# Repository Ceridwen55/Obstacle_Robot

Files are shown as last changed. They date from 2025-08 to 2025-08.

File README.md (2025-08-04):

## 🤖 Wall Avoiding Robot (TM4C1294XL + PWM + Sharp IR Sensor)

A lightweight wall-avoiding robot built with the TM4C1294XL LaunchPad, using real analog sensor data and low-level embedded programming. No RTOS ( I dont think I need to implement this due to simple scheduling situation ), no Arduino. Just C, timers, ADCs, and PWM. Great for learning direct hardware control. I'm mixing DRM and TivaWare due to ADC RIS didn't work with my intention with using DRM only method, so that's that

---

## 🚀 Overview

The robot moves forward and avoids obstacles using two DC motors and two Sharp IR sensors. It reads distance on the left and right, calculates the error, and adjusts each motor's PWM speed to steer accordingly.

It uses:

- **SysTick timer** for generating PWM
- **ADC0 Sequencer 2** to read analog values from Sharp GP2Y0A21YK0F sensors (PE2 and PE3)
- **Bare-metal C programming** using TivaWare API
- **Empirical distance calibration formula** to convert ADC values into actual distance

---

## 📐 Core Logic

1. **PWM control using SysTick:**  
   Timer fires at 16 kHz. Each motor gets a PWM signal. PWM values are updated based on the sensor readings.

2. **Analog sensor readings (ADC):**  
   PE2 and PE3 (AIN1 and AIN0) are used for right and left distance sensors. ADC sequencer 2 reads both at once.

3. **Distance calculation:**  
   Distance (cm) = 114251 / ADC_Value
(Empirically derived constant for GP2Y0A21YK0F)

## Decision-making:
The difference between left and right distance determines motor speed difference. 

Logic:

If the robot is too close on one side → slow that side's motor

If both sides are balanced → move forward

## 🧠 Behavior Table

Condition	Action
error > 100	Turn left (slow right motor)
error < -100	Turn right (slow left motor)
-100 <= error <= 100	Move forward (equal speed)

## 📦 Hardware Bill of Materials (BoM)

| Component | Quantity | Notes |
|---|---|---|
| TM4C1294XL LaunchPad | 1 | Main MCU board |
| DC Motors (3–7V, F130 type) | 2 | For driving the wheels |
| Sharp IR Sensor (GP2Y0A21YK0F) | 2 | Distance sensing front-left and front-right|
| IRLB3034 / TIP120 Transistors | 2 | Motor driver (TIP120 used due to logic voltage compatibility) | ( *Yup this is too far right lol* )
| Diode 1N4002 | 2 | Flyback protection |
| Capacitor 10µF | 2 | Noise filtering |
| L7805CV Voltage Regulator | 1 | For 5V output to sensors & MCU |
| Resistor 220Ω | 2 | Gate resistor for transistor |
| Resistor 10kΩ | 2 | Pull-down on transistor gate |
| LM2596 Buck Converter | 1 | Optional for efficient power delivery |
| Li-Ion Batteries (3.7V) | 3 | Power source |
| Battery Holder (3-slot) | 1 | For 3S battery configuration |
| Robot chassis + wheels | 1 set | WD dual wheel kit or similar |

## 🛠️ Software Highlights

- `PLL_Init()`  
Sets system clock to 120 MHz to allow fast ADC + PWM cycles

- `GPIOA_Init()`  
Initializes PA4 and PA5 as PWM-controlled motor outputs

- `GPIOE_Init()`  
Prepares PE2 and PE3 as analog inputs for the IR sensors

- `ADC0_Sequencer2_Init_SoftwareTrigger()`  
Uses Sequencer 2 with 2 steps to read both sensors

- `SysTick_Handler()`  
PWM generation and timing logic using hardware timer

- `Robot_Logic()`  
Core decision-making: steer left/right based on distance error

- `ADC_READ()`  
Read analog voltages, convert to digital values, apply distance formula

---

## 📏 Behavior

| Error Value (Right - Left) | Action |
|---|---|
| > 100 | Turn left (right slower) |
| < -100 | Turn right (left slower) |
| -100 ≤ error ≤ 100 | Go straight (equal speed) |

*Note: Values like `8200`, `6000`, etc. in SysTick PWM represent high-time portion out of 12000 total ticks (i.e., 60%, 50% duty cycle).*

---

## ⚙️ To-Do / Possible Improvements

- [ ] Stop completely if both distances are very short (e.g. wall directly ahead)
- [ ] Add LED indicators or debug UART for status reporting
- [ ] Add hysteresis for smoother turning
- [ ] Add PID-style control instead of simple threshold error
- [ ] VACUUMM CLEANERRRR
- [ ] Voice Assistant so at least I've got someone to talk when my Wife's working hehe ( I'm  going to make this cute robot on the next project using ESP32 instead so stay tuneee (I know this is hard but, LETS GOOO :))) )

---

## 🧪 Requirements

- TivaWare SDK
- ARM GCC or Code Composer Studio ( I'm using Keil uVision here )
- Due to DRM Method, it's exclusive on TM4C1294XL from Texas Instrument
- Soldering gear (if using PCB )
- Oscilloscope / logic analyzer (optional but useful, but I dont have one avail right now *cry*)

---

## 📷 Coming Soon

- Photos of the actual robot
- Short demo video
( You can see the project updates on my linkedin page here https://www.linkedin.com/in/muhammad-zaqzulkan/ )

---

## 💡 Inspiration

A mix of old-school analog robotics and low-level microcontroller programming ( honestly, it's Wall-E, really ). It’s a nice weekend project to brush up on embedded C, register-level config, and real-time logic. By the way, this is one of the first complex project that I'm just working on for my porto.

---

## 🛜 License

MIT License — free to use, modify, and share. If you build your own version or remix it, feel free to share back improvements ( I want to add another power source and a vacuum to be a vacuum cleaner robot due to my unbelievable laziness )

---

Thanks for checking out my simple project! Stay tune for my next project.

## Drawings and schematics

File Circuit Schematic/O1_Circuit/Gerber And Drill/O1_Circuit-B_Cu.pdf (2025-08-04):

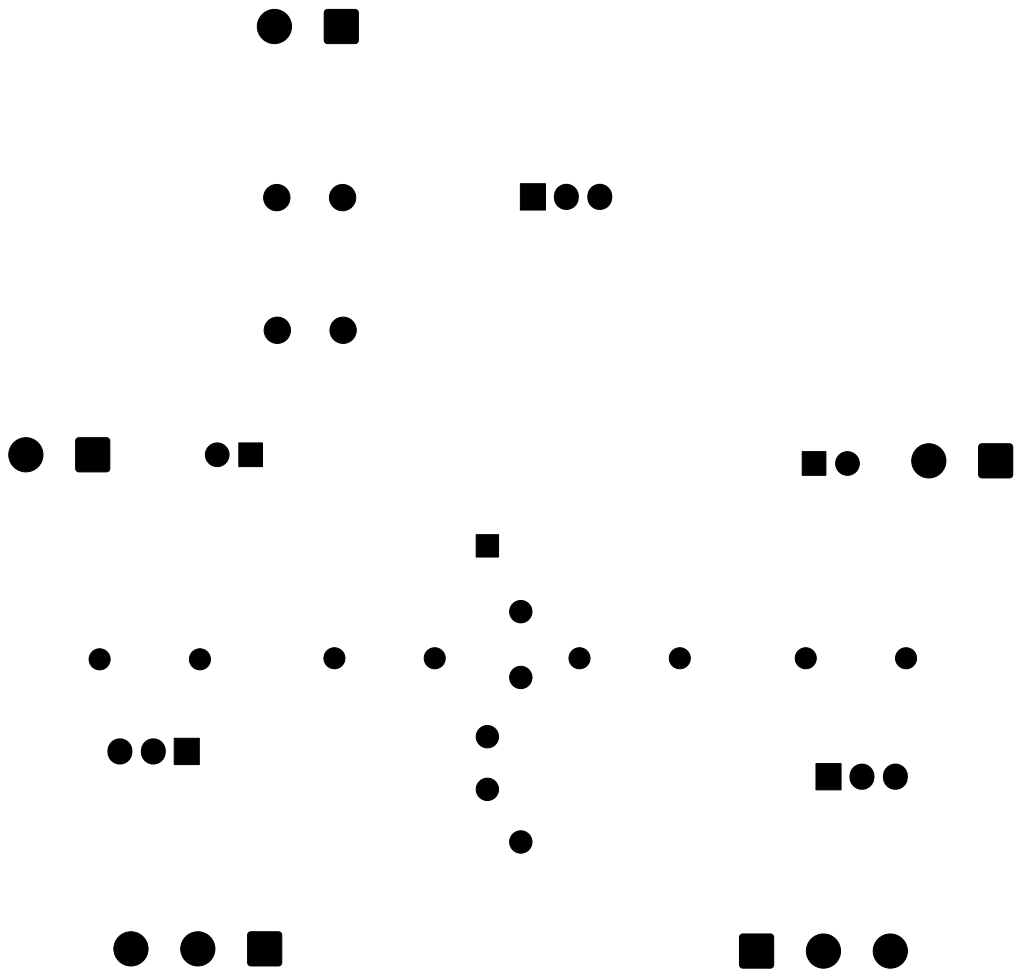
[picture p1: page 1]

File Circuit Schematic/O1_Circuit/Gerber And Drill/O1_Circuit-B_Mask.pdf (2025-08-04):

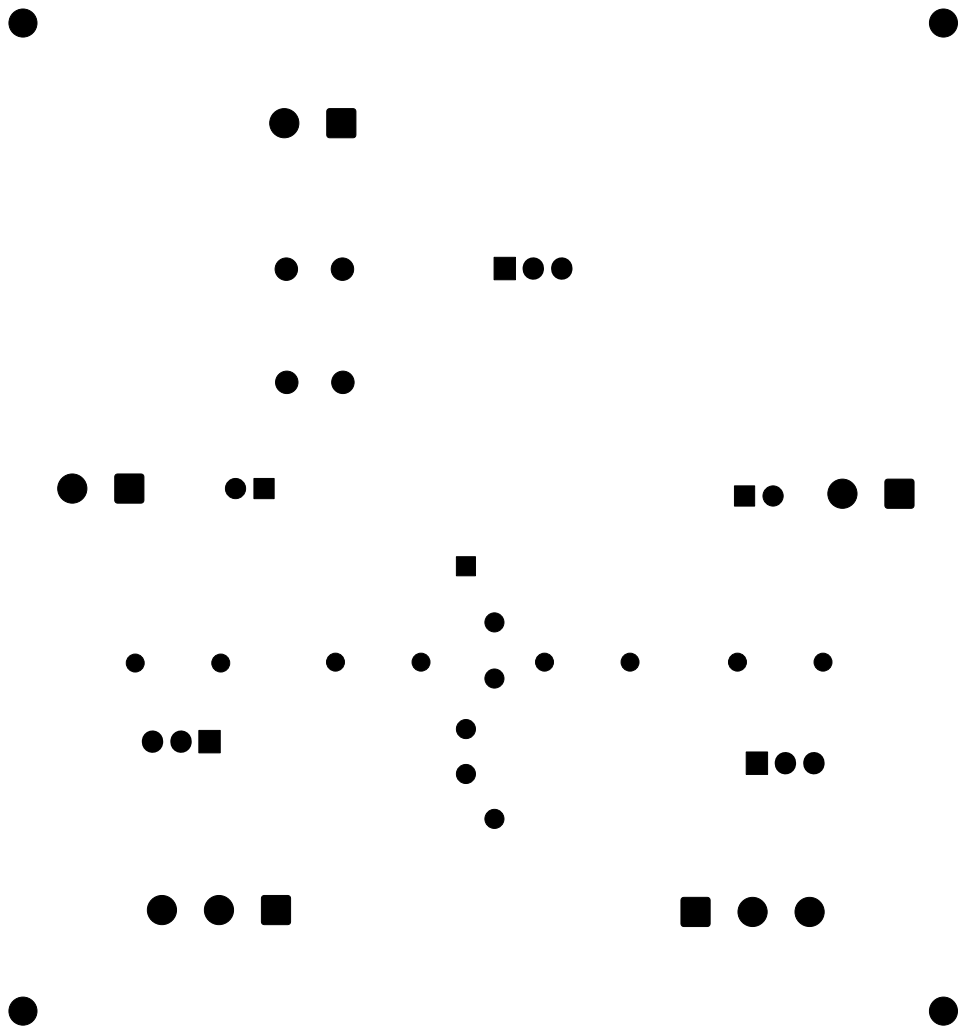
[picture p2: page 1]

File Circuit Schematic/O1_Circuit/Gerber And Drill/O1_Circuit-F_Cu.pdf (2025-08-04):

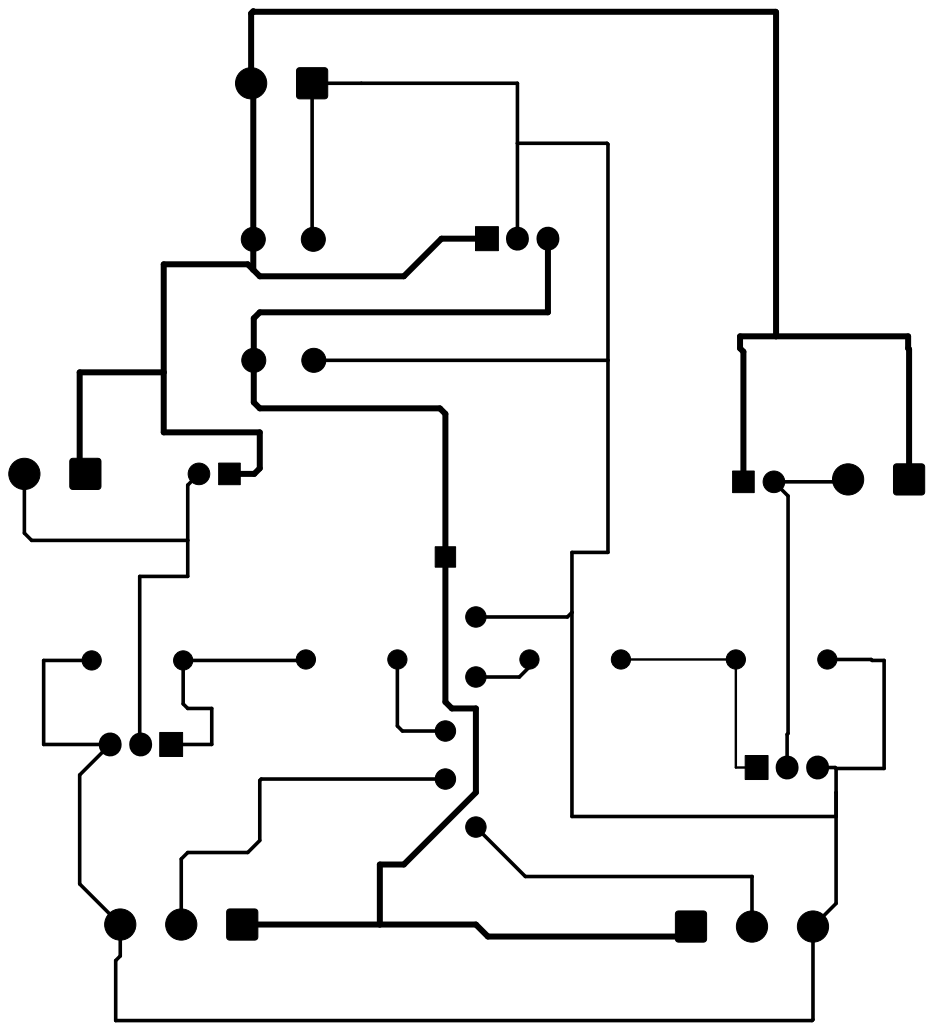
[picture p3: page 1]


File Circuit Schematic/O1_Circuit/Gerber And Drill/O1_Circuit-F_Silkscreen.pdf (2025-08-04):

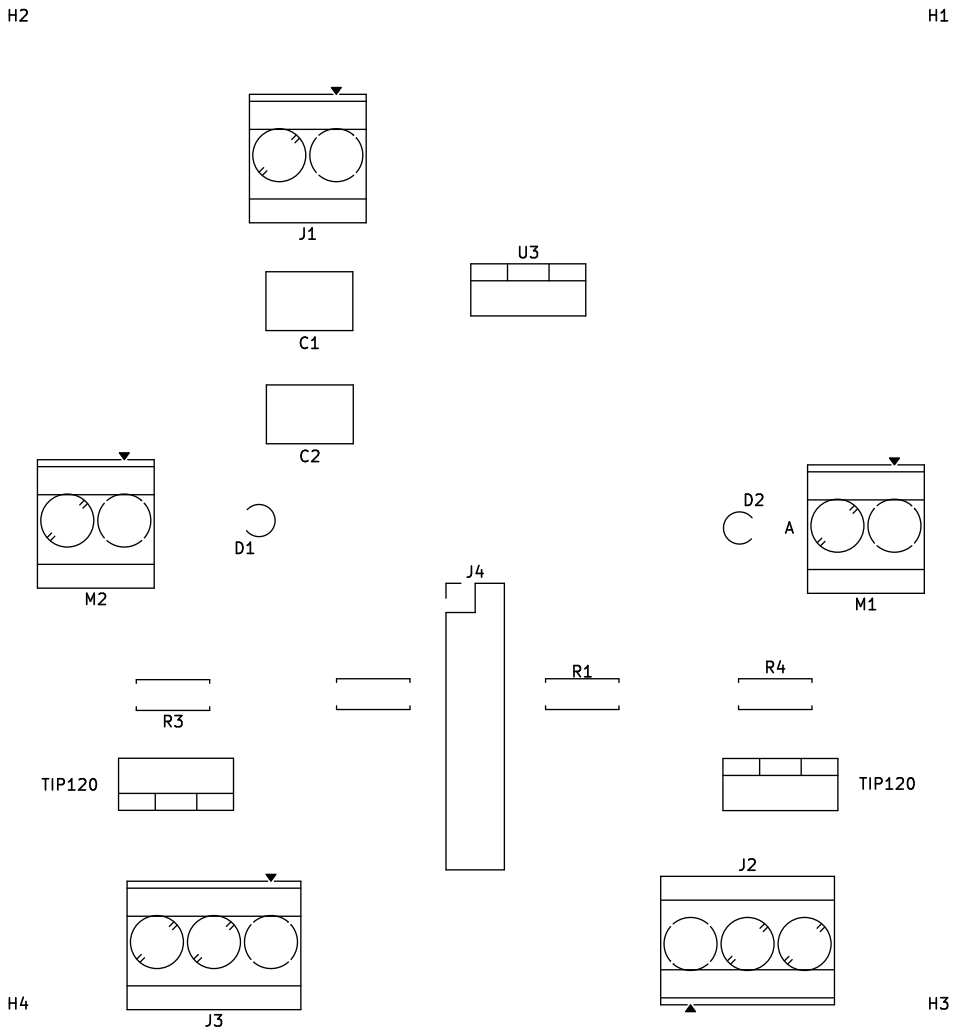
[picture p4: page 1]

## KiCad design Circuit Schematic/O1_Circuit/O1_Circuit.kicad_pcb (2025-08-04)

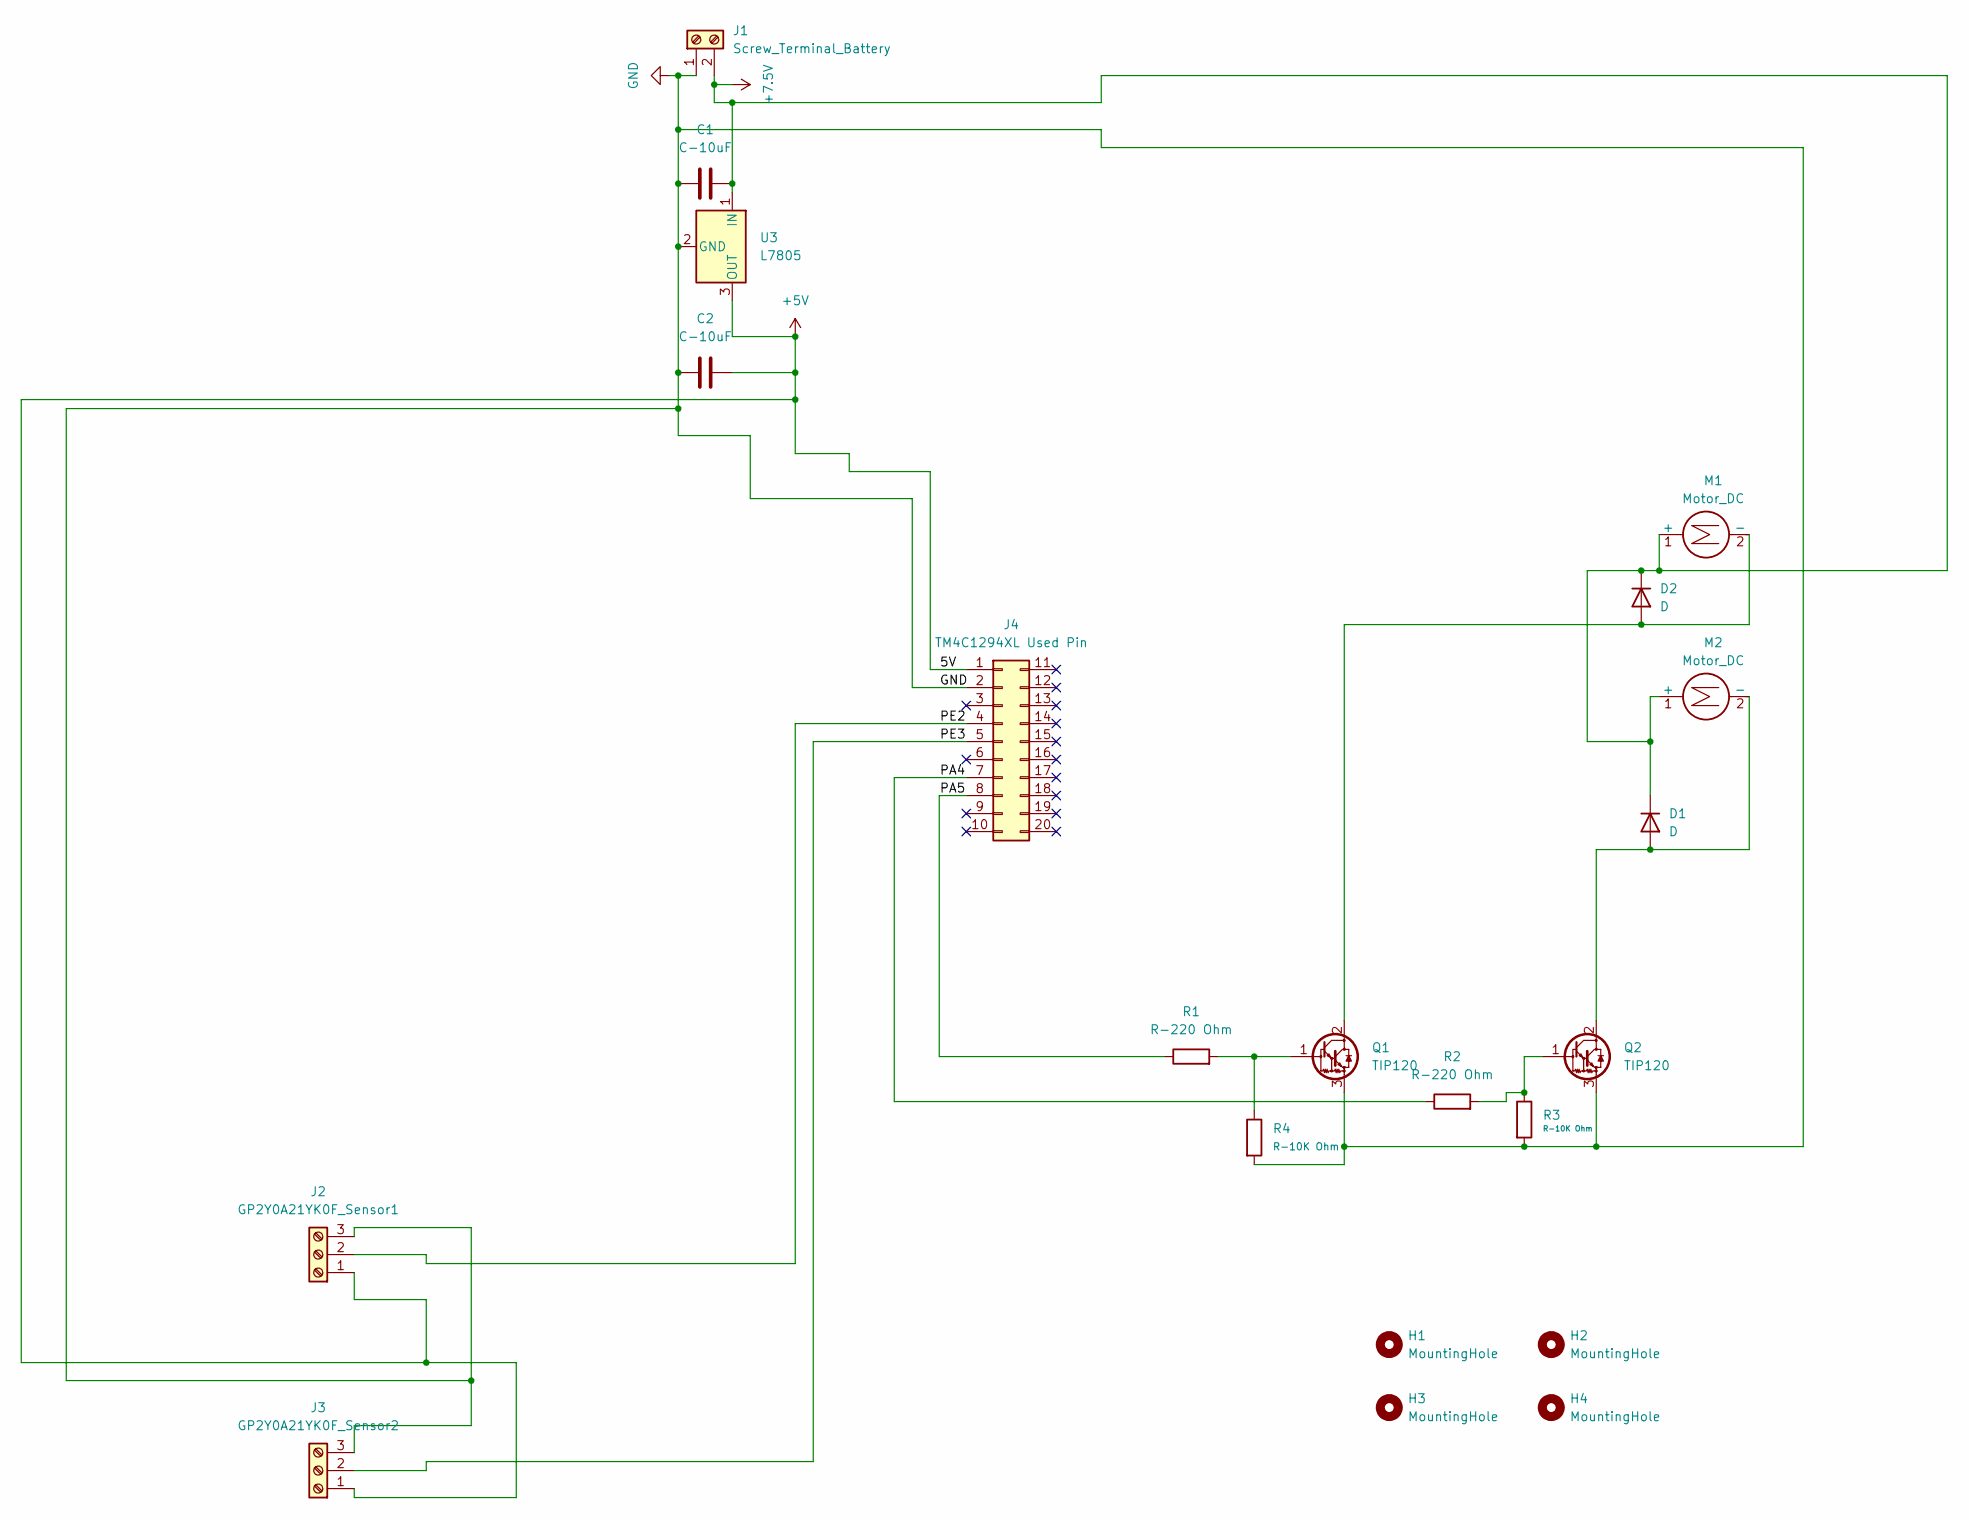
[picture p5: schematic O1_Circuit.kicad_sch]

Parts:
C1, C2: C-10uF; C_Disc_D7.5mm_W5.0mm_P5.00mm
D1, D2: D; D_A-405_P2.54mm_Vertical_AnodeUp
H1, H2, H3, H4: MountingHole; MountingHole_2.5mm
J1: Screw_Terminal_Battery; TerminalBlock_Phoenix_MKDS-3-2-5.08_1x02_P5.08mm_Horizontal
J2: GP2Y0A21YK0F_Sensor1; TerminalBlock_Phoenix_MKDS-3-3-5.08_1x03_P5.08mm_Horizontal
J3: GP2Y0A21YK0F_Sensor2; TerminalBlock_Phoenix_MKDS-3-3-5.08_1x03_P5.08mm_Horizontal
J4: TM4C1294XL Used Pin; PinHeader_2x10_P2.54mm_Vertical
M1, M2: Motor_DC; TerminalBlock_Phoenix_MKDS-3-2-5.08_1x02_P5.08mm_Horizontal
Q1, Q2: TIP120; TO-220-3_Vertical
R1, R2: R-220 Ohm; R_Axial_DIN0207_L6.3mm_D2.5mm_P7.62mm_Horizontal
R3, R4: R-10K Ohm; R_Axial_DIN0207_L6.3mm_D2.5mm_P7.62mm_Horizontal
U3: L7805; TO-220-3_Vertical

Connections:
+5V: C2.2, J2.1, J3.1, J4.1, U3.3 (OUT)
+7.5V: C1.2, D1.1 (K), D2.1 (K), J1.2, M1.1 (+), M2.1 (+), U3.1 (IN)
/PA4: J4.7, R2.1
/PA5: J4.8, R1.1
/PE2: J2.2, J4.4
/PE3: J3.2, J4.5
GND: C1.1, C2.1, J1.1, J2.3, J3.3, J4.2, Q1.3 (E), Q2.3 (E), R3.2, R4.2, U3.2 (GND)
unnamed: D1.2 (A), M2.2 (-), Q2.2 (C)
unnamed: D2.2 (A), M1.2 (-), Q1.2 (C)
unnamed: Q1.1 (B), R1.2, R4.1
unnamed: Q2.1 (B), R2.2, R3.1

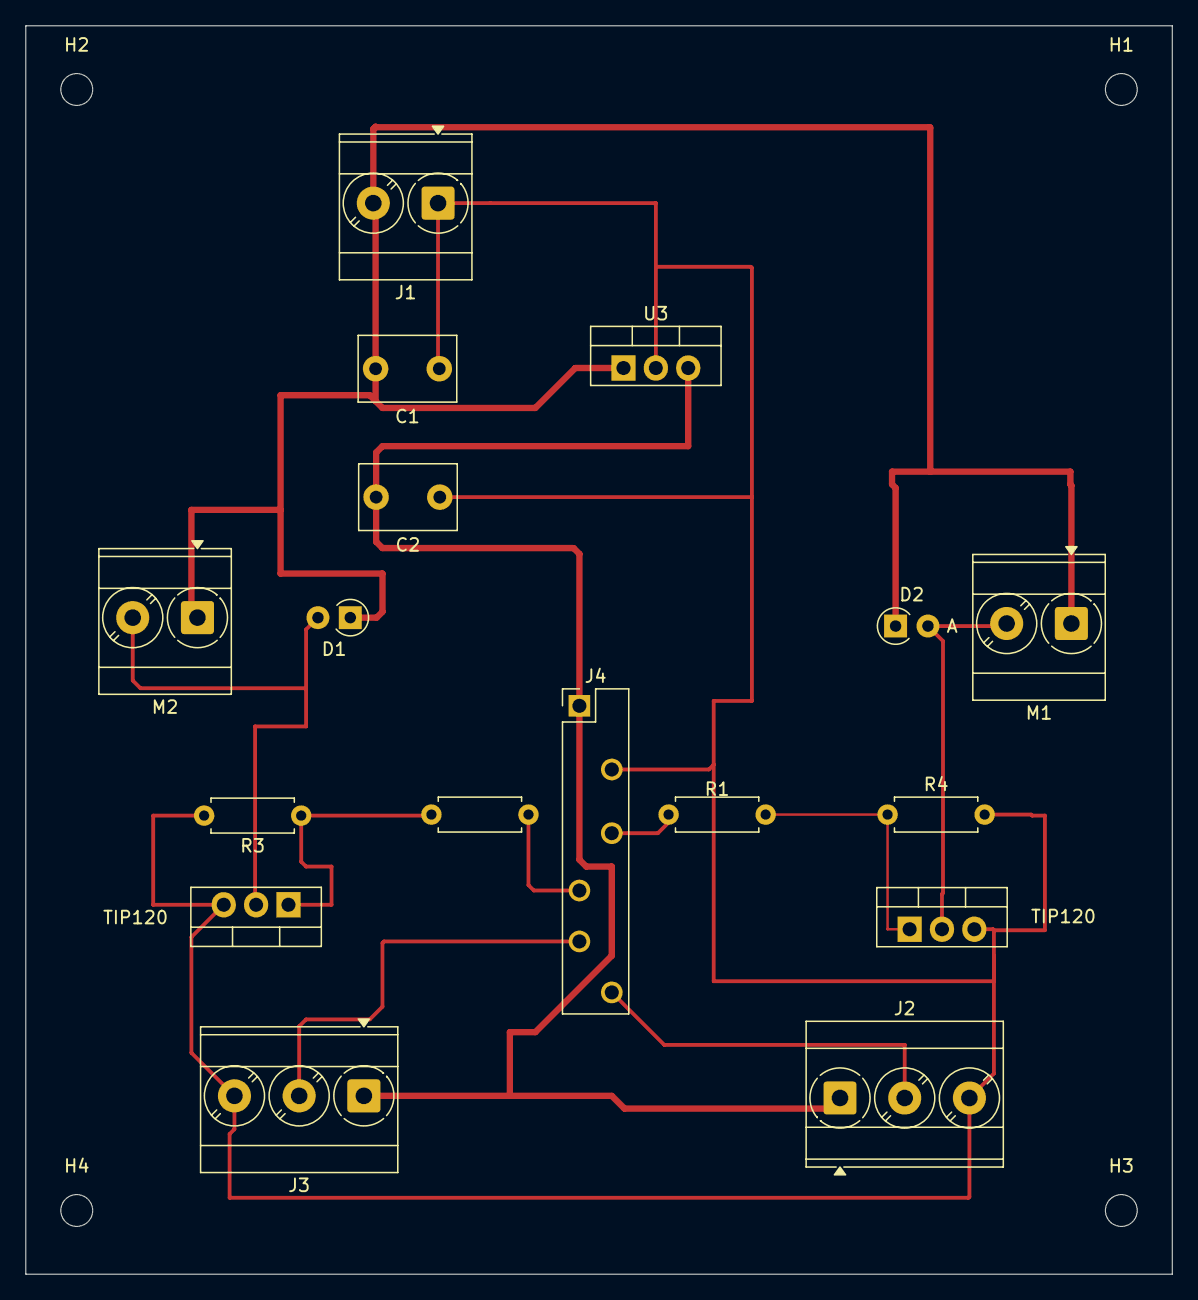
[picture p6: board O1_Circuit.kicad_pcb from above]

Board: 2 copper layers, 90.0 x 98.0 mm, 21 parts (0 on the bottom side), 11 nets.

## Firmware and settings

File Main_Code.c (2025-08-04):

//*** GENERAL VIEW OF THE PROJECT ***//

/*
Create a simple robot that can handle obstacle and keep moving forward. Using PWM to control the DC Motor based on the data received from the distance sensors attached at the front of the robot.
*/

//*** SOFTWARE DESIGN ** //

/*

1. Set GPIO as the output to control 2 DC Motors ( 4-24 V ) (PA4 and PA5)

2. Set GPIO as the input from the distance sensors (Sharp GP2Y0A21YK0F) (Right now, PE3 and PE2 for AIN0 and AIN1)

3. Set the PWM function using Systick to automate and control the DC motors PWM
 - Using Systick to control the PWM at right and left DC motors
 - Minimum PWM is 30% on each DC Motor ( High 30%, Low 70%), and Maximum PWM is 60% on each the DC motor, standard is 50%
 - We set the NVIC Reload value for the H+L is 16000, because we need 16000 cycle per second or 16 KHz to make the rotation smoother ( PLL base freq change to 120 Mhz to accomodate ADC conversion, 120.000.000 cycles per second)
 - We will get the analog value from the distance sensor and convert it to digital value in another function, based on that statement, we will control the PWM if it should turn right or left or stay
 - We will use this main formula to determine the 'turn', Error = DistanceLeft - DistanceRight

4. Create the 2 ADC Function to convert the analog value to digital value so we can use that to determine the robot's judgment
 - Based on the empirical calibration, we found that contant number for ADC value to Real distance is 114251, so the formula is Distance = 114251 / ADC value from sensor
 - Because we are using TM4C1294XL, we use 12 bit ADC so the ADC value range will be from 0 to 4095 ( cause of 12 bit, therefore 4096 possibilities can happen)
 - After conversion, we will return the Distance value so it can be used to control each the DC motor PWM

5. After distance value is returned by the ADC function, make Robot_Logic function
 - Based on the previous point (3), based on the error, if error is 0 then there is no need to turn right/left ( keep going straight )
 - Lets say if error is 10 , because left is bigger than right (+) ( probably because right sensor is closer to the wall/obstacle of course) the Right DC motor PWM will be decreased and left Dc motor PWM will be increased 
 - If error is 0, turn back the DC motor into standard PWM so it will move straight
 - Lets say if error is -10 , right is bigger than left (-), the left DC motor PWM will be decreased and Right DC motor PWM will be increased
 - The problem is if the track is relatively safe to move straight but there are 2 walls with different distance from the sensor, we need to find the limitation for the robot logic to work smoothly without bug

6. Polish the software as needed

*/

//*** HARDWARE DESIGN AND BOM ***//

/*

1. PCB will be designed in KiCad and printed to subtitute breadboards and jumpers

2. DC Motor Circuit
	- 2 DC Motors 3-7V Model F130( actuators )
	- 2 Distance Sensors Sharp GP2Y0A21YK0F ( sensors )
	- 3 LiOn Battery 3.71 V ( power source ) and one set of 3-battery slot
	- 2 Capacitors 10 micro farad ( Controlling noise from input and output )
	- 1 regulator L7805CV ( Regulating voltage from 11.13 v source to Vin MCU and sensors )
	- 2 Transistors MOSFET IRLB3034 ( Logic control from MCU to Motors ) / Change to TIP 120 cause MCU Voltage not enough to activate IRLB3034
	- 2 Diodes 1N4002 ( Protect MCU )
	- 2 220 Ohm resistors ( protect GPIO to gate Transistor)
	- 2 10k Ohm resistors ( pull down so it will stabilize motor while MCU turns on )
	- 1 LM2596 DC-DC
	
3. Robot Body and Attachment
	- 2 wheels attached to the DC Motors 78MM Dual Shaft( choose with the good friction and low load for the motor to spin)
	- 2 WD Casis kit


Changes of plan :
- Im going to use TivaWare API on ADC because its always error on reading the ADC RIS register value with DRM method
- 

*/




#include <stdint.h>
#include <stdbool.h>
#include "inc/hw_memmap.h"
#include "driverlib/sysctl.h"
#include "driverlib/gpio.h"
#include "driverlib/adc.h"
#include "driverlib/systick.h"
#include "driverlib/interrupt.h"
#include "inc/hw_ints.h"


//*** ADDRESS ***//

//CLOCK
#define SYSCTL_RCGCGPIO_R       (*((volatile uint32_t *)0x400FE608)) //RCGCGPIO Address offset 0x608
#define SYSCTL_RCGCADC_R        (*((volatile uint32_t *)0x400FE638)) //RCGCADC Address offset 0x638
#define SYSCTL_PRGPIO_R         (*((volatile uint32_t *)0x400FEA08)) //Peripheral Ready GPIO Address offset 0xA08
#define SYSCTL_PRADC_R          (*((volatile uint32_t *)0x400FEA38)) //Peripheral Ready ADC Address offset 0xA38

//GPIO A

#define GPIO_PORTA_DATA_R       (*((volatile uint32_t *)0x400043FC)) //Offset 0x3fc
#define GPIO_PORTA_DIR_R        (*((volatile uint32_t *)0x40004400)) //Offset 0x400
#define GPIO_PORTA_PUR_R        (*((volatile uint32_t *)0x40004510)) //Offset 0x510
#define GPIO_PORTA_DEN_R        (*((volatile uint32_t *)0x4000451C)) //Offset 0x51c
#define GPIO_PORTA_DR8R					(*((volatile uint32_t *)0x40004508)) //Offset 0x508

//NVIC
#define NVIC_STCTRL_R						(*((volatile uint32_t *)0xE000E010)) //Offset 0x010
#define NVIC_STRELOAD_R					(*((volatile uint32_t *)0xE000E014)) //Offset 0x014
#define NVIC_STCURRENT_R				(*((volatile uint32_t *)0xE000E018)) //Offset 0x018
#define NVIC_SYS_PRI3_R  				(*((volatile uint32_t *)0xE000E40C)) //PRI3 because SysTick interrupt ( OFFSET 0X40C)
	
	
//GPIO E

#define GPIO_PORTE_DATA_R			 (*((volatile uint32_t *)0x400243FC)) //Offset 0x3fc
#define GPIO_PORTE_DIR_R			 (*((volatile uint32_t *)0x40024400)) //Offset 0x400
#define GPIO_PORTE_DEN_R			 (*((volatile uint32_t *)0x4002451C)) //Offset 0x51C
#define GPIO_PORTE_AMSEL_R		 (*((volatile uint32_t *)0x40024528)) //Offset 0x528
#define GPIO_PORTE_AFSEL_R		 (*((volatile uint32_t *)0x40024420)) //Offset 0x420

//ADC0

#define ADC0_ACTSS				 	   (*((volatile uint32_t *)0x40038000)) //Offset 0x000
#define ADC0_EMUX				 	     (*((volatile uint32_t *)0x40038014)) //Offset 0x014
#define ADC0_SSPRI				 	   (*((volatile uint32_t *)0x40038020)) //Offset 0x020
#define ADC0_SSMUX2				 	   (*((volatile uint32_t *)0x40038080)) //Offset 0x080
#define ADC0_SSCTL2				 	   (*((volatile uint32_t *)0x40038084)) //Offset 0x084
#define ADC0_IM				 	       (*((volatile uint32_t *)0x40038008)) //Offset 0x008
#define ADC0_PC				 	       (*((volatile uint32_t *)0x40038FC4)) //Offset 0xFC4
#define ADC0_PSSI			 	   		 (*((volatile uint32_t *)0x40038028)) //Offset 0x028
#define ADC0_RIS				 	   	 (*((volatile uint32_t *)0x40038004)) //Offset 0x004
#define ADC0_SSFIFO2				 	 (*((volatile uint32_t *)0x40038088)) //Offset 0x088
#define ADC0_ISC				 	     (*((volatile uint32_t *)0x4003800C)) //Offset 0x00C


//*** PROTOTYPE ***//



//*** GLOBAL VARIABLE ***///

volatile uint32_t counter_pwm = 0;
volatile uint32_t standard_high_left;
volatile uint32_t standard_high_right;
volatile uint32_t sensor_value[2];

volatile uint32_t distance_right;
volatile uint32_t distance_left;



//**FUNCTIONS**//
// Enable global interrupts
void EnableInterrupts(void) {
    __asm("CPSIE I");  // CPSIE I = Clear Interrupt Disable bit, enabling interrupts
}

// Wait for interrupt 
void WaitForInterrupts(void) {
    __asm("WFI");  // WFI = Wait For Interrupt instruction
}

void PLL_Init(void)
{
	uint32_t sys_clk = SysCtlClockFreqSet((SYSCTL_XTAL_25MHZ | SYSCTL_OSC_MAIN | SYSCTL_USE_PLL | SYSCTL_CFG_VCO_480),120000000);
}

void GPIOA_Init (void)
{
	SYSCTL_RCGCGPIO_R |= 0x01;  //0000 0001 , turn on Port A clock
	while ((SYSCTL_RCGCGPIO_R & 0x01) == 0);
	GPIO_PORTA_DIR_R |= 0x30; //0011 0000, PA4 and PA5 as output
	GPIO_PORTA_DEN_R |= 0x30; //0011 0000, PA4 and PA5 use digital funct
	GPIO_PORTA_DR8R |= 0x30; //0011 0000, PA4 and PA5 has 8mA drive ( for dc motor amps)
	GPIO_PORTA_DATA_R &= ~0x30; //1100 1111, set PA4 and PA5 off so Systick Handler got benchmark on what to do next
}

void GPIOE_Init (void)
{
	SysCtlPeripheralEnable(SYSCTL_PERIPH_GPIOE); //0001 000"1", turn on port E clock yet not disturbing previous setup on Port A
  while (!SysCtlPeripheralReady(SYSCTL_PERIPH_GPIOE));
	GPIO_PORTE_DEN_R &= ~0x0C; // Disable digital PE2, PE3
	GPIO_PORTE_AFSEL_R |= 0x0C; // 0000 1100, PE3 and PE2 alternative funct on ( no need to setup dir cause already analog mode )
	GPIO_PORTE_AMSEL_R |= 0x0C; //0000 1100, PE3 and PE2 analog funct on
	
}

void ADC0_Sequencer2_Init_SoftwareTrigger (void)
{
	 SysCtlPeripheralEnable(SYSCTL_PERIPH_ADC0); //Turn on Sysctl for ADC0
   while(!SysCtlPeripheralReady(SYSCTL_PERIPH_ADC0)); //Stabilize the clock first
   ADCSequenceDisable(ADC0_BASE, 2); //Disable seq2
   ADCSequenceConfigure(ADC0_BASE, 2, ADC_TRIGGER_PROCESSOR, 0);
   
   ADCSequenceStepConfigure(ADC0_BASE, 2, 0, ADC_CTL_CH1); // Step 0: AIN1 (PE2)
   
   ADCSequenceStepConfigure(ADC0_BASE, 2, 1, ADC_CTL_CH0 | ADC_CTL_IE | ADC_CTL_END); // Step 1: AIN0 (PE3) + IE + END

   ADCSequenceEnable(ADC0_BASE, 2); //Enable Seq 2
   ADCIntClear(ADC0_BASE, 2); // Clear
	
	
	
	/*
	DRM Method didn't work =
	SYSCTL_RCGCADC_R |= 0x01; //0000 0001, turn on ADC0
	while(!SysCtlPeripheralReady(SYSCTL_PERIPH_ADC0));
	ADC0_PC &= ~0xF; //reset all bits to 0 for ADCPC reg
	ADC0_PC |= 0x01; //set to 128 Khz, why? cause delay 112 Tadc, with average 13 Tadc for conversion to happen, so if ADC clock 16 Mhz / 125 = 128 kHz
	ADC0_SSPRI = 0x1023; // 1 for SS3, 0 for SS2, 2 for SS1, 3 for SS0. Smaller the number, higher the priority so SS2 is the highest
	ADC0_ACTSS &= ~0x04; //Disable Sample Sequencer 2 ( SS2)
	ADC0_EMUX &= ~0x0F00; //Software Trigger for seq 2
	ADC0_SSMUX2 = 0x01 | 0x00; //1 for AIN1 because PE2 at bit 0-3 at step 0, 0 for AIN0 because PE3 at bit 4-7 at step 1
	ADC0_SSCTL2 = 0x06 | 0x60; // IE0 and END0 for step 0 and IE1 and END1 for step 1
	ADC0_IM &= ~0x04; // disable interrupt mask for SS2
	ADC0_ACTSS |= 0x04; //enable sample sequencer 2 again
	*/
	
}

void SysTick_Init (void)
{
	NVIC_STCTRL_R = 0;
	NVIC_STRELOAD_R = 12000 - 1; //Standard freq is 120.000.000, we need 10 kHz per PWM 100% or 100 micro seconds cause 1 tick is 8.33 nano seconds, so reload value is 12000 - 1
	NVIC_STCURRENT_R = 0;
	NVIC_STCTRL_R = 0x07;
	NVIC_SYS_PRI3_R = (NVIC_SYS_PRI3_R & 0x00FFFFFF) | 0x20000000; //Priority 1
}



void Robot_Logic (void)
{

	distance_right = 114251 / sensor_value[0]; 
	distance_left = 114251 / sensor_value[1];
  int32_t error = distance_right - distance_left;
	
		
  if (error > 100) 
	{
    standard_high_right = 8200; // 60%
    standard_high_left = 3800;  // 40%
  }
  else if (error < -100) 
	{
    standard_high_left = 8200; // 60%
    standard_high_right = 38300; // 40%
  }
  else 
	{
    standard_high_left = 6000; // 50%
    standard_high_right = 6000; // 50%
  }

	
}

void ADC_READ(void)
{	 
	 uint32_t adc_vals[2];
	
   ADCProcessorTrigger(ADC0_BASE, 2);
   while (!ADCIntStatus(ADC0_BASE, 2, false));
   ADCSequenceDataGet(ADC0_BASE, 2, adc_vals);
   ADCIntClear(ADC0_BASE, 2);
	 sensor_value[0] = adc_vals[0]; // PE2 converted distance
   sensor_value[1] = adc_vals[1]; // PE3 converted distance

	
	
	
 /*
 DRM didn't work = 
 ADC0_PSSI = 0x04; //Activate SS2
 while((ADC0_RIS&0x04)==0){}; //if not 0 (its one), it will proceed the looping
 right_sensor= ADC0_SSFIFO2 & 0xFFF;
 left_sensor = ADC0_SSFIFO2 & 0xFFF;
 distance_right = 241814 / right_sensor; //returning distance that is the result of result divided by empirical constant (241814)
 distance_left = 241814 / left_sensor; //returning distance that is the result of result divided by empirical constant (241814)
 ADC0_ISC = 0x04; //clear interrupt flag for SS2
*/
}

void SysTick_Handler (void) //here we are using SysTick to help collecting Data and control the PWM of the DC Motor
{
	
	counter_pwm = (counter_pwm + 1) % 12000;
	
		
  if(counter_pwm < standard_high_right)
      GPIO_PORTA_DATA_R |= 0x10;
  else
      GPIO_PORTA_DATA_R &= ~0x10;

  if(counter_pwm < standard_high_left)
      GPIO_PORTA_DATA_R |= 0x20;
  else
      GPIO_PORTA_DATA_R &= ~0x20;
	
}

	
int main (void)
{
	PLL_Init();
	GPIOA_Init();
	GPIOE_Init();
	SysTick_Init();
	ADC0_Sequencer2_Init_SoftwareTrigger();
	EnableInterrupts();
	while(1)
	{	
		ADC_READ();
		Robot_Logic();
	}
}

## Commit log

2025-06-18 Adding hardware BOM part 1
2025-06-21 Finishing setting up ADC sampling
2025-06-22 Experimenting with independent PWM
2025-06-26 Progressing on schematic
    [O1_Circuit.kicad_pcb, O1_Circuit.kicad_sch]
2025-06-26 Almost finished with Schematic
    [O1_Circuit.kicad_sch]
2025-07-02 Begin Prototyping
    [O1_Circuit.kicad_sch]
2025-07-07 Hybrid using API TivaWare Due to ADC error DRM
    [Main_Code.c]
2025-07-14 Hybrid with TivaWare API due to error ADC
    [Main_Code.c]
2025-07-21 Fixing Schematic and Start desigbing PCB
    [O1_Circuit.kicad_pcb, O1_Circuit.kicad_sch]
2025-07-23 Fiishing PCB
    [O1_Circuit.kicad_pcb, O1_Circuit.kicad_sch]
2025-07-23 Touch up PCB
    [O1_Circuit.kicad_pcb]
2025-07-29 PCB Design Edit
    [O1_Circuit-B_Cu.gbr, O1_Circuit-B_Mask.gbr, O1_Circuit-B_Paste.gbr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]
2025-08-02 Editing PCB due to short on prev
    [O1_Circuit.kicad_pcb, O1_Circuit.kicad_sch]
2025-08-04 Calibrating Distance Sensor Obstacle Detection
    [O1_Circuit-B_Cu.gbr, O1_Circuit-B_Mask.gbr, O1_Circuit-B_Paste.gbr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]
